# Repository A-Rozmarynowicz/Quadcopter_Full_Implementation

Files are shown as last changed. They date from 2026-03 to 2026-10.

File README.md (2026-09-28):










# Design and implementation of a quadrotor with a localization algorithm based on Ultra-Wideband beacons.

My Bachelor's project's task is to build a quadcopter from scratch, implement control and trajectory planning algorithms, synthesize a mathematical model, and develop an indoor positioning system. The expected outcome is a functional, maneuverable, and stable drone that is able to follow given trajectories.

Development time: from 01.2026 to 02.2027 (expected).

The project is also referred to as "Day One".

<p align="center">
  <picture>
    <source media="(prefers-color-scheme: dark)" srcset="Graphics\Logos\DayOne_Logo_White_on_Github.png">
    <source media="(prefers-color-scheme: light)" srcset="Graphics\Logos\DayOne_Logo_Black_on_White.png">
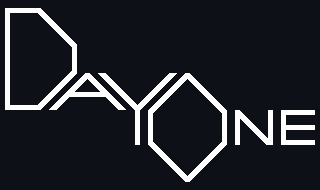
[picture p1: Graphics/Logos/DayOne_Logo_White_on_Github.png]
    
  </picture>
</p>

## Table of contents
* [Current progress](#current-progress)
* [General Information](#general-information)
* [UWB Positioning System](#uwb-positioning-system)
* [Technologies Used](#technologies-used)

## Current progress

The quadcopter has been assembled and it passed all the necessary hardware tests. That means the motors work, all chips are soldered correctly, and nothing is overheating. It lifts at around 35% motor power, and the battery lasts around 5 minutes in that setting. The machine is visible below.

<p align="center">
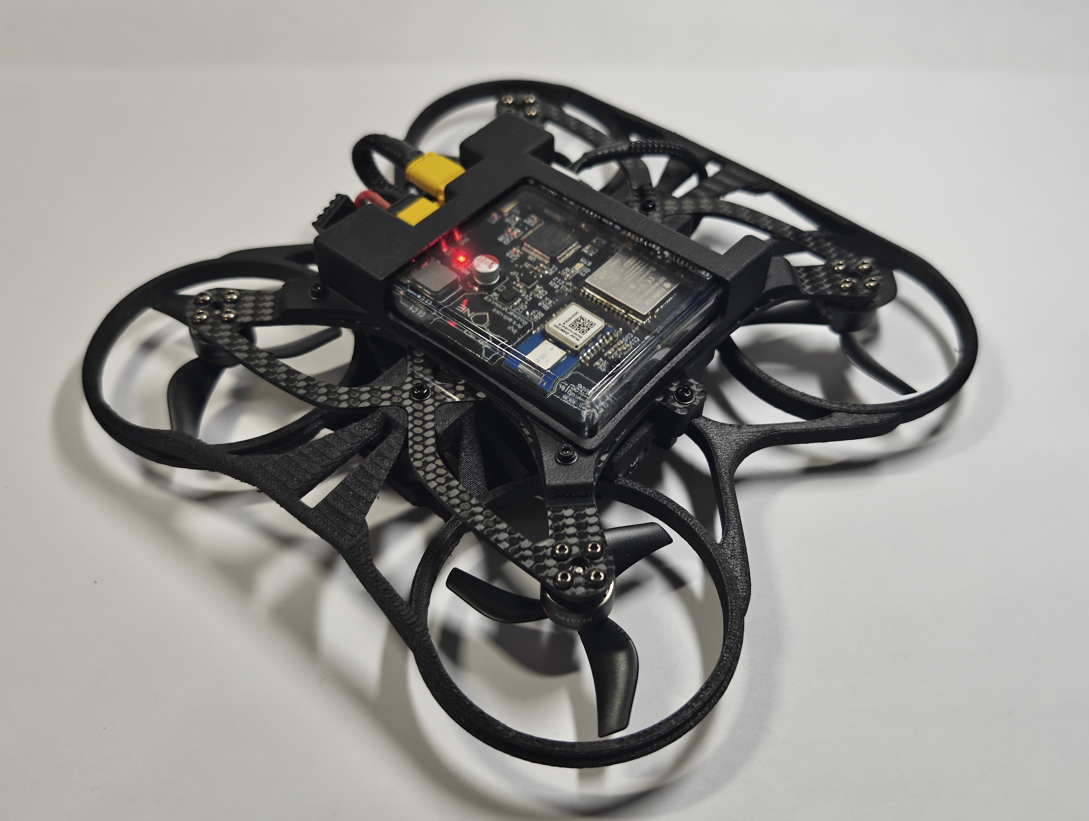
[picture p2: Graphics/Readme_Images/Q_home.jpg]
 <br>
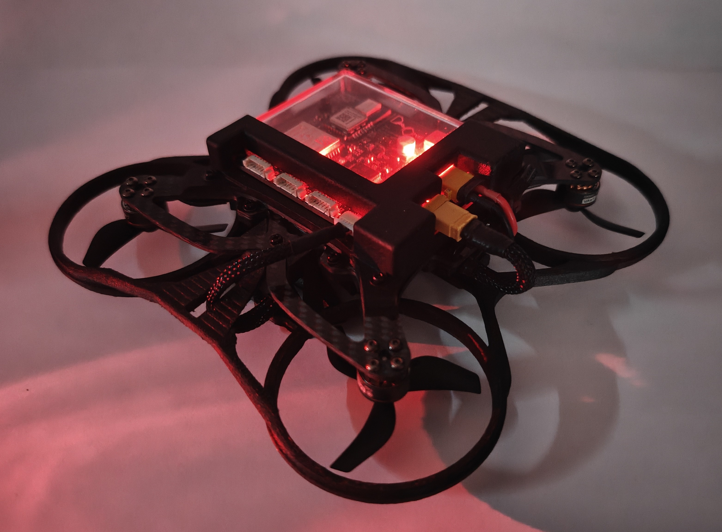
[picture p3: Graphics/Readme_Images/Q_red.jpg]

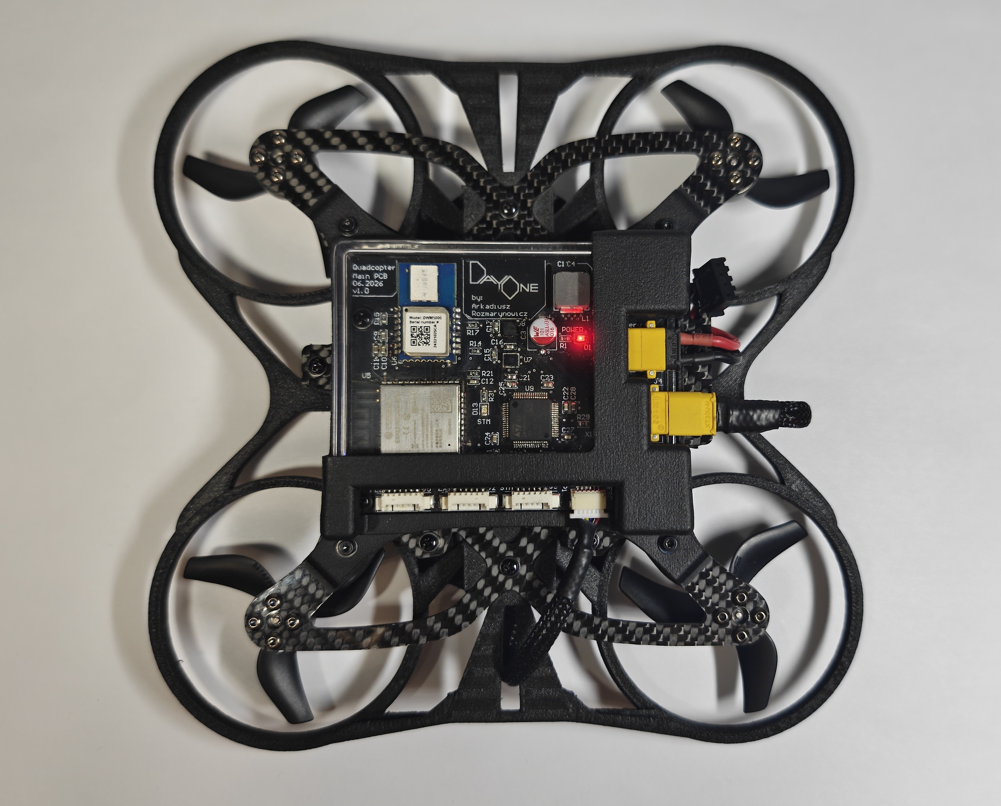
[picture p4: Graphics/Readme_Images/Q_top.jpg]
 <br>
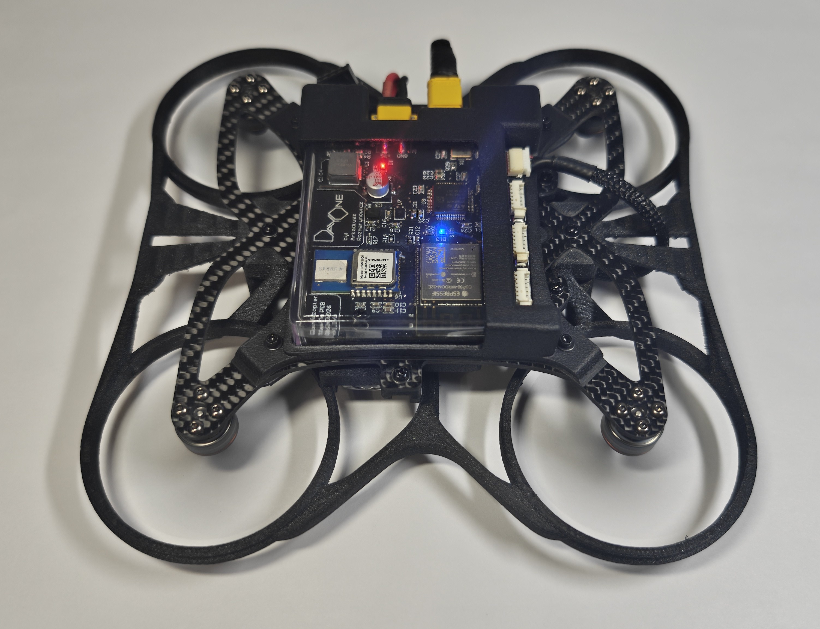
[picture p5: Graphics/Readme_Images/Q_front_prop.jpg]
 <br>
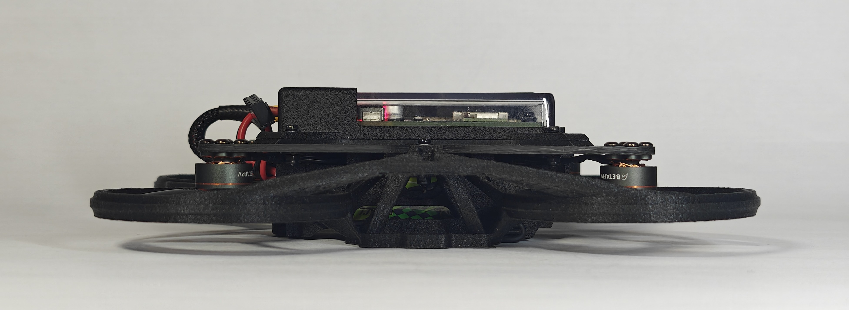
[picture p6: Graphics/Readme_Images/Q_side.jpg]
 <br>
<em>Figure 1: Quadcopter in real life.</em>
 </p>

The main PCB, visible in Figure 2, has been soldered manually and tested. The schematic document is available in this file: [.../Quadcopter_Main_PCB_Schematic.pdf](./Hardware/Electronics/Documents/Datasheets/Quadcopter_Main_PCB_Schematic.pdf).

<p align="center">
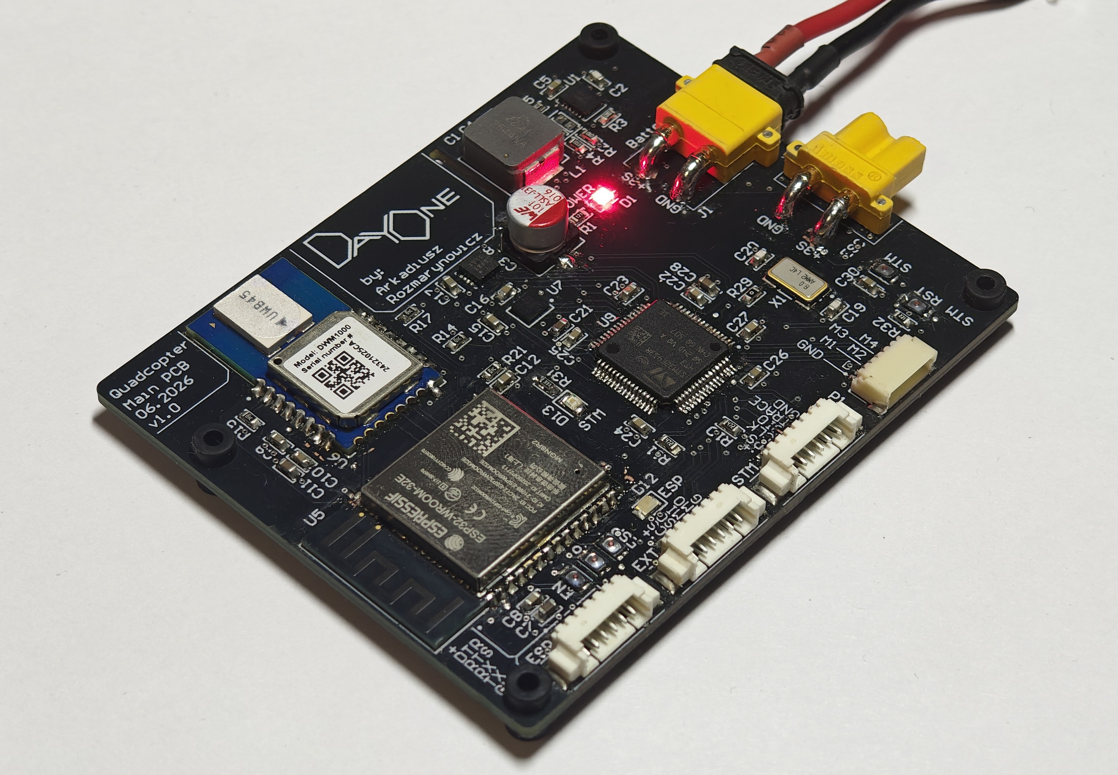
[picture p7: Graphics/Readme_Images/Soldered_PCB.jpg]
 <br>
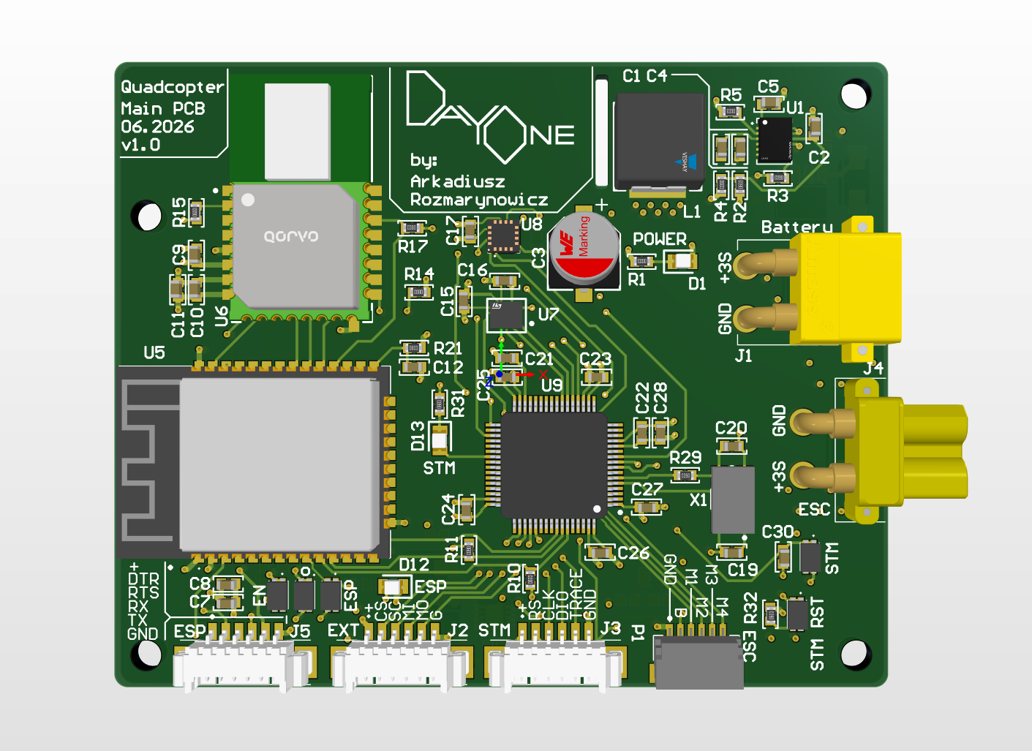
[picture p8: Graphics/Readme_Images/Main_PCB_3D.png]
Main PCB
 <br>
<em>Figure 2: 3D view of the quadcopter main PCB.</em>
 </p>

The current 3D model of the quadcopter is visible in Figure 3.

<p align="center">
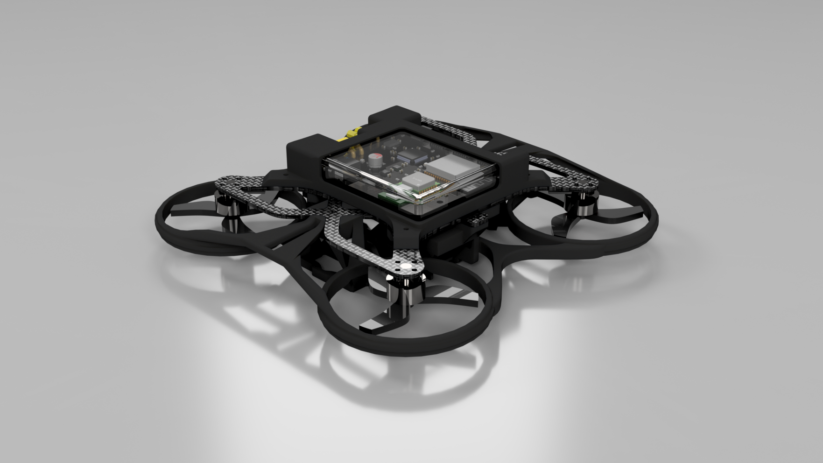
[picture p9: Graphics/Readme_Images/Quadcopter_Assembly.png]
Quadcopter Render
 <br>
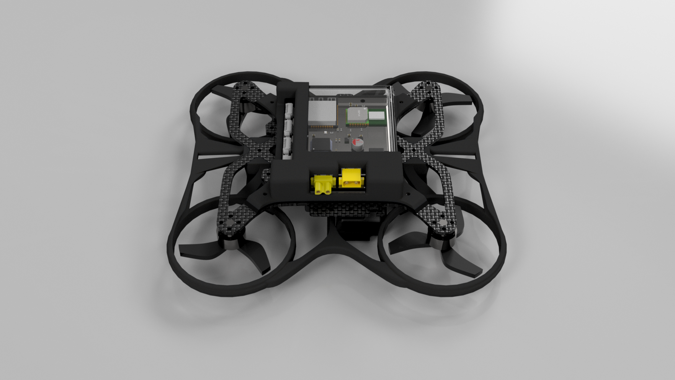
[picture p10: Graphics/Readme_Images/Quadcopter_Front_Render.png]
Quadcopter Render
 <br>
<em>Figure 3: 3D model of the quadcopter.</em>
 </p>

## General information

### Control Engineering
- Implementing a:
    - cascade 4-loop PID controller,
    - Kalman filter state estimator.
    - If time allows: polynomial decoupled trajectory planning based on given setpoints,
- Utilizing quaternions for attitude representation enabling more stable orientation control.
- If time allows: synthesizing a mathematical model of the drone to enable tuning the algorithms in simulation.
- Enabling manual override of the speed or attitude commands.

### Electronics
- An STM32F4 is used as the main MCU.
- An ESP32 onboard provides communication with a ground station and a custom positioning system (described later).
- IMU and a magnetometer support the positioning system in state estimation.
- Power source is a 680mAh, 3S, LiHV, lightweight, and small battery.
- Propellers are mounted on BLDC motors for high efficiency and power.
- The onboard power converter steps the voltage down to 3.3V.
- Safety measures are implemented to protect the device from overcurrent, overvoltage, reverse polarity, and ESD events.
- An off-the-shelf ESC drives the motors, commanded by the MCU's DShot signals.

### Mechanics
- Designing a custom:
    - carbon base plate for the robot,
    - housing for the PCBs,
    - shielding frame around the propellers,
    - battery slot.
- Total weight turned out to be 242 grams, which fits within the constraints set by the propellers' thrust: the drone lifts at around 35% motor power.

## UWB Positioning System
Part of the project is a custom positioning system that doesn't rely on a GPS signal. This is achieved by placing at least 4 Ultra-Wideband (UWB) modules near the area of the drone's operation. They measure their distance to the robot and estimate its relative position. This system is almost fully developed, and can be seen in this repository: [https://github.com/A-Rozmarynowicz/UWB_Positioning_System](https://github.com/A-Rozmarynowicz/UWB_Positioning_System).

<p align="center">
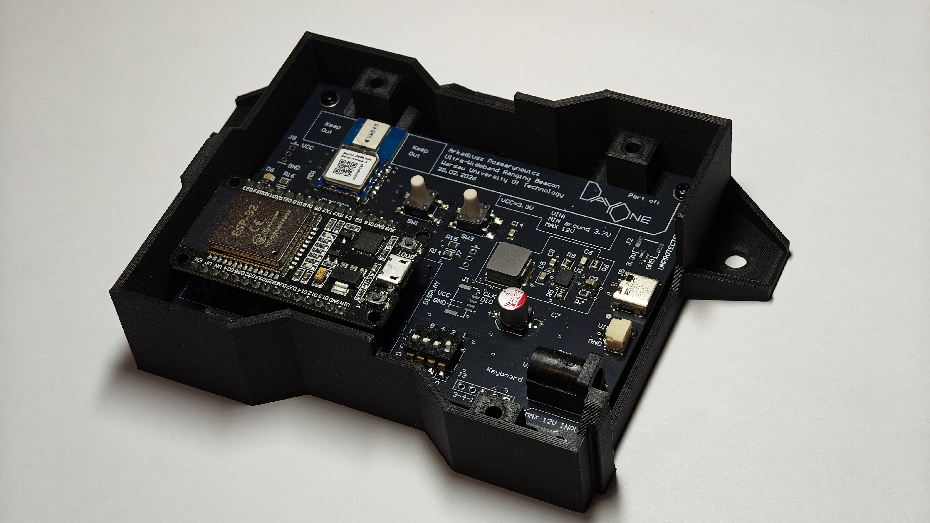
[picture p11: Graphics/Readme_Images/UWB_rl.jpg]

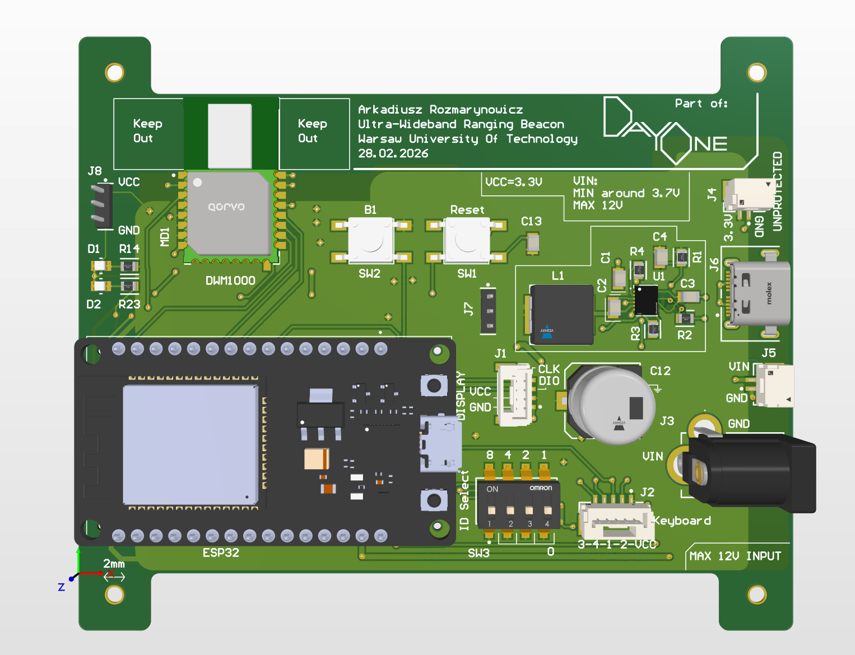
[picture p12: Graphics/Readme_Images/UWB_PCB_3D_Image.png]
 <br>
<em>Figure 4: UWB anchor.</em>
 </p>

## Technologies Used
- Ultra-Wideband radio technology
- Multiple communication protocols: SPI, I2C, UART, ESP-NOW, DShot
- Control engineering:
    - cascade PID
    - polynomial decoupled trajectory calculation
    - Kalman filter

- Programming languages:
    - C
    - C++
    - MATLAB

- Software used:
    - STM32 Cube IDE
    - Altium Designer
    - Autodesk Fusion
    - MATLAB
    - PlatformIO

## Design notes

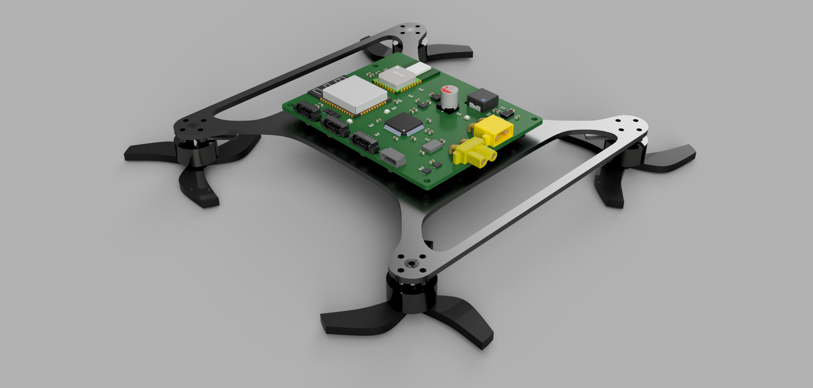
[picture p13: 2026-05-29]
Graphics/Readme_Images/Quadcopter_Frame_View.png

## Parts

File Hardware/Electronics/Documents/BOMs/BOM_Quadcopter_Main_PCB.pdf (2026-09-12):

Line # | Designator | Value | Quantity Part Number | Package | Supplier
13 | C1, C8, C9, C10, C12, C13, C14, C15, C16, C22, C23, C24, C25, C26, C27, C29, C30 | 100nF | 17 CC0603KRX7R8BB104 | 0603 | Mouser
15 | C2 | 27pF | 1 CC0603JRNP09BN270 | 0603 | Mouser
16 | C3 | 100µF | 1 865080545012 | | Mouser
12 | C4 | 4.7uF | 1 06035U4R7JAT2A | 0603 | Mouser
14 | C5, C17 | 1uF | 2 CC0603KRX5R6BB105 | 0603 | Mouser
17 | C6 | 22uF | 1 CC0603MRX6S4BB226 | 0603 | Mouser
1 | C7, C11, C28 | 2.2uF | 3 06036G225ZAT2A | 0603 | Mouser
18 | C18 | 10uF | 1 C0603C106M7PAC7411 | 0603 | Mouser
19 | C19, C20 | 30pF | 2 06031A300FAT2A | 0603 | Mouser
20 | C21 | 4.7uF | 1 06035U4R7JAT2A | 0603 | Mouser
23 | D1, D12, D13 | | 3 LS R976 | | Mouser
21 | D2, D3 | | 2 SMAJ12CA-HP6AT/13 | | Mouser
2 | D4, D6, D8, D9 | | 4 RCLAMP3354S.TCT | | Mouser
3 | D5, D7 | | 2 SMAJ12CA-HP6AT/13 | | Mouser
22 | D10 | | 1 ZMM33B | | Mouser
4 | D11 | | 1 AQ1205-01LTG | | Mouser
24 | F1 | | 1 0603L100SLYR | | Mouser
25 | J1 | | 1 XT30PW-M
5 | J2, J3, J5 | | 3 53261-0671 | | Mouser
26 | J4 | | 1 XT30PW-F
27 | L1 | | 1 IHLP3232DZER220M51 | | Mouser
6 | P1 | | 1 SM06B-SRSS-TB(LF)(SN) | | Mouser
29 | Q1, Q2 | | 2 SS8050-G | | Mouser
32 | R1, R26, R31 | 120R | 3 CR0603-JW-121ELF | 0603 | Mouser
30 | R2, R3, R5, R13 | 100k | 4 AF0603FR-13100KL | 0603 | Mouser
31 | R4 | 22.1k | 1 CRCW060322K1FKEBC | 0603 | Mouser
33 | R6, R7, R14, R15, R16, R17, R18, R19, R20, R21, R22, R23, R28, R30 | 10k | 14 CR0603AFX-1002EAS | 0603 | Mouser
7 | R8, R9, R24, R25, R27, R32, R33 | 220R | 7 CR0603-JW-221ELF | 0603 | Mouser
35 | R10, R11 | 4.7k | 2 AC0603JR-104K7L | 0603 | Mouser
34 | R12 | 270k | 1 CR0603-JW-274ELF | 0603 | Mouser
8 | R29 | 0R | 1 CR0603AJ/-000ELF | 0603 | Mouser
40 | SW1, SW2, SW3, SW4, SW5 | | 5 USLPT2616CT2TR | | Mouser
36 | U1 | | 1 ISL85410FRZ-T | | Mouser
37 | U2 | | 1 STEF4SPUR | | Mouser
38 | U3, U4 | | 2 DMP3056LSS-13 | | Mouser
9 | U5 | | 1 ESP32-WROOM-32E-N8R2 | | Mouser
28 | U6 | | 1 DWM1000 | | TME
39 | U7 | | 1 LSM6DSOTR | LGA-14L-DM00249496 Mouser
10 | U8 | | 1 MMC5983MA | | Mouser
11 | U9 | | 1 STM32F413RHT3 | | Mouser
41 | X1 | | 1 ABMM2-8.000MHZ-E2-T | | Mouser

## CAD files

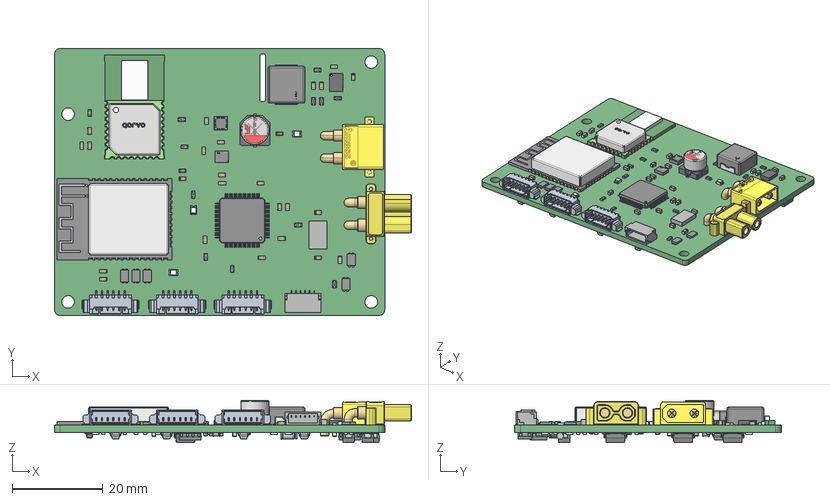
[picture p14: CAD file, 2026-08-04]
Hardware/Mechanics/PCBs/Quadcopter_Main_PCB.step
78.9 x 59.0 x 9.39 mm
capicitor_6.3x5.5x2.2
Base_Φ6_3Capacitor
0603 resistor x 33
terminal
pcb
antenna
pcb top
logo x 2
0603 cap x 29
ZMM33B
RCLAMP3354S.TCT x 4
SM06B-SRSS-TB_RGB8421504
AQ1205-01LTG
Pins x 5
Extruded
LS_R976 x 3
STM32F413RHT3
base
terminals
Logo x 2
MMC5983MA
Pieza141
Pieza142
Pieza143
Pieza143_10
Pieza143_26
Pieza143_44
Pieza143_17
Pieza143_21
Pieza143_37
Pieza143_35
Pieza143_16
Pieza143_3
Pieza143_18
Pieza143_5
Pieza143_31
Pieza143_33
Pieza143_2
Pieza143_4
Pieza143_34
Pieza143_24
Pieza143_15
Pieza143_22
Pieza143_36
Pieza143_32
Pieza143_6
Pieza143_19
Pieza143_23
Pieza143_41
Pieza143_7
Pieza143_20
Pieza143_38
Pieza143_11
Pieza143_8
Pieza143_39
Pieza143_40
Pieza143_9
Pieza143_25
Pieza143_42
Pieza143_43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

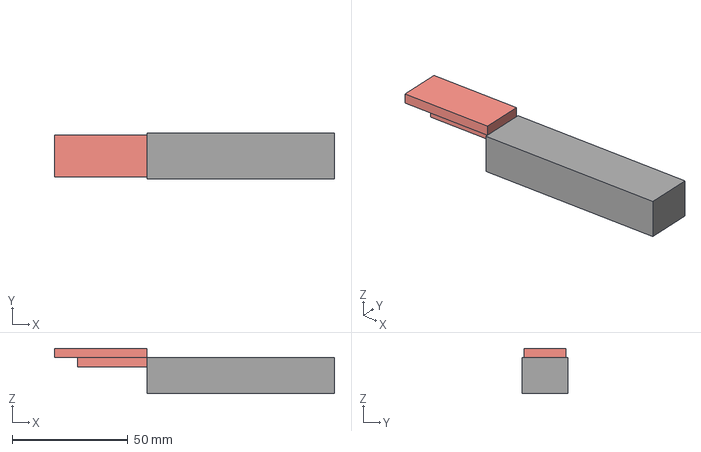
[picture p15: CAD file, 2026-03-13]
Hardware/Mechanics/Batteries/Battery_LAVA 2_3S_680mAh.step
121.0 x 20.0 x 19.5 mm

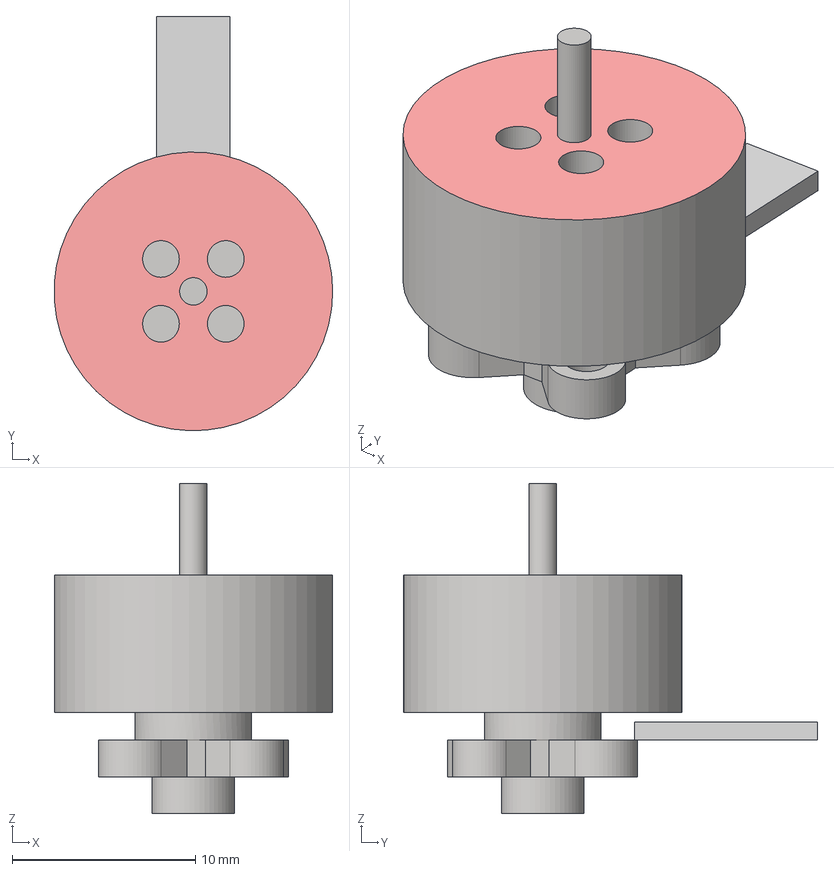
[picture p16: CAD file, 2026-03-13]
Hardware/Mechanics/Motors/BLDC_1104_7200KV.step
15.2 x 22.6 x 18.0 mm

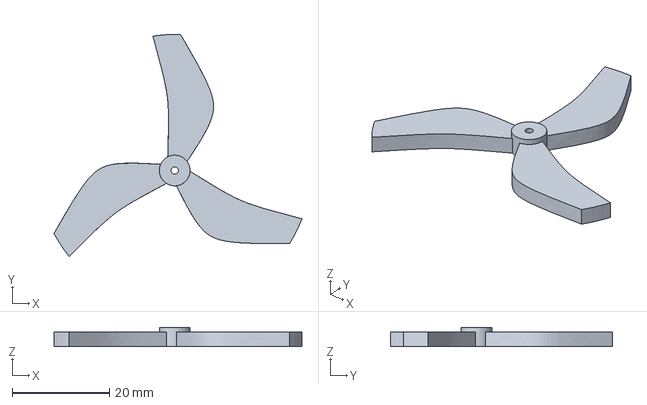
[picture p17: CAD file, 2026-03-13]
Hardware/Mechanics/Propellers/2218_3Blade/Propeller_2218_3Blade.step
50.9 x 45.6 x 4.00 mm

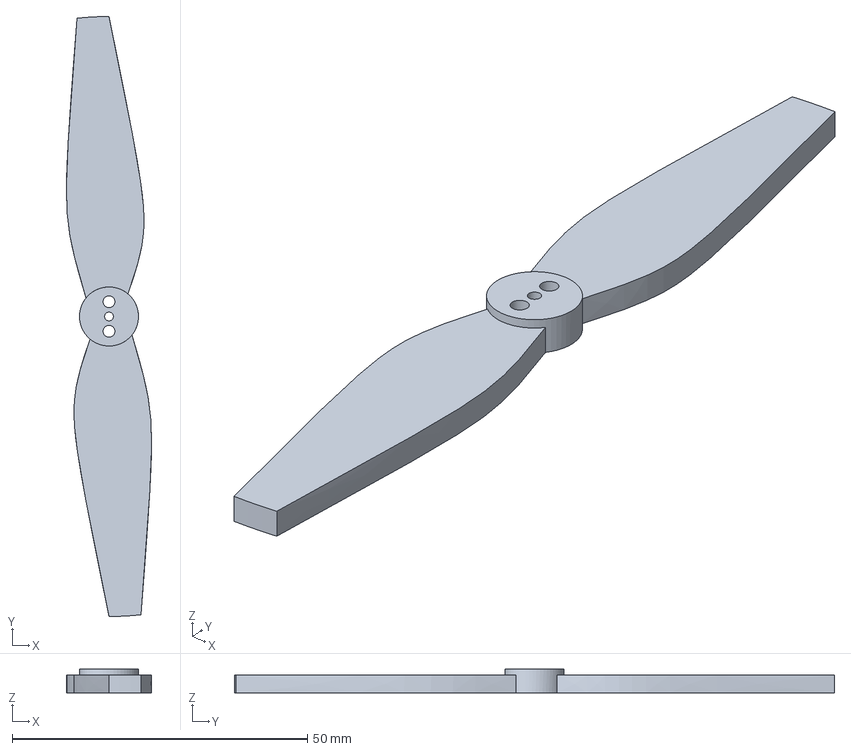
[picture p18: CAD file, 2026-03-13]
Hardware/Mechanics/Propellers/4025_2Blade/Propeller_4025_2Blade.step
14.4 x 101.6 x 4.00 mm

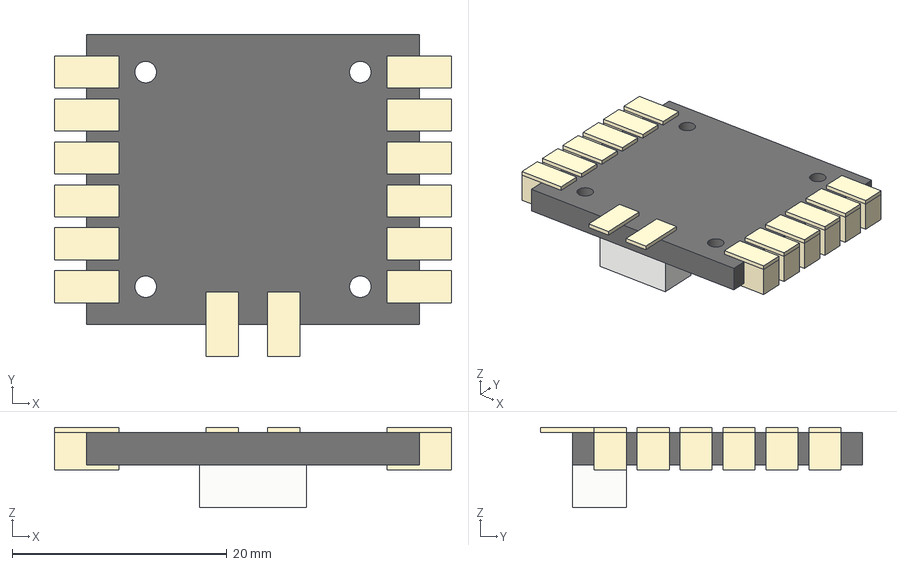
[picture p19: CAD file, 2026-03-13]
Hardware/Mechanics/PCBs/ESC_HAKRC_20A.step
37.0 x 30.0 x 7.50 mm

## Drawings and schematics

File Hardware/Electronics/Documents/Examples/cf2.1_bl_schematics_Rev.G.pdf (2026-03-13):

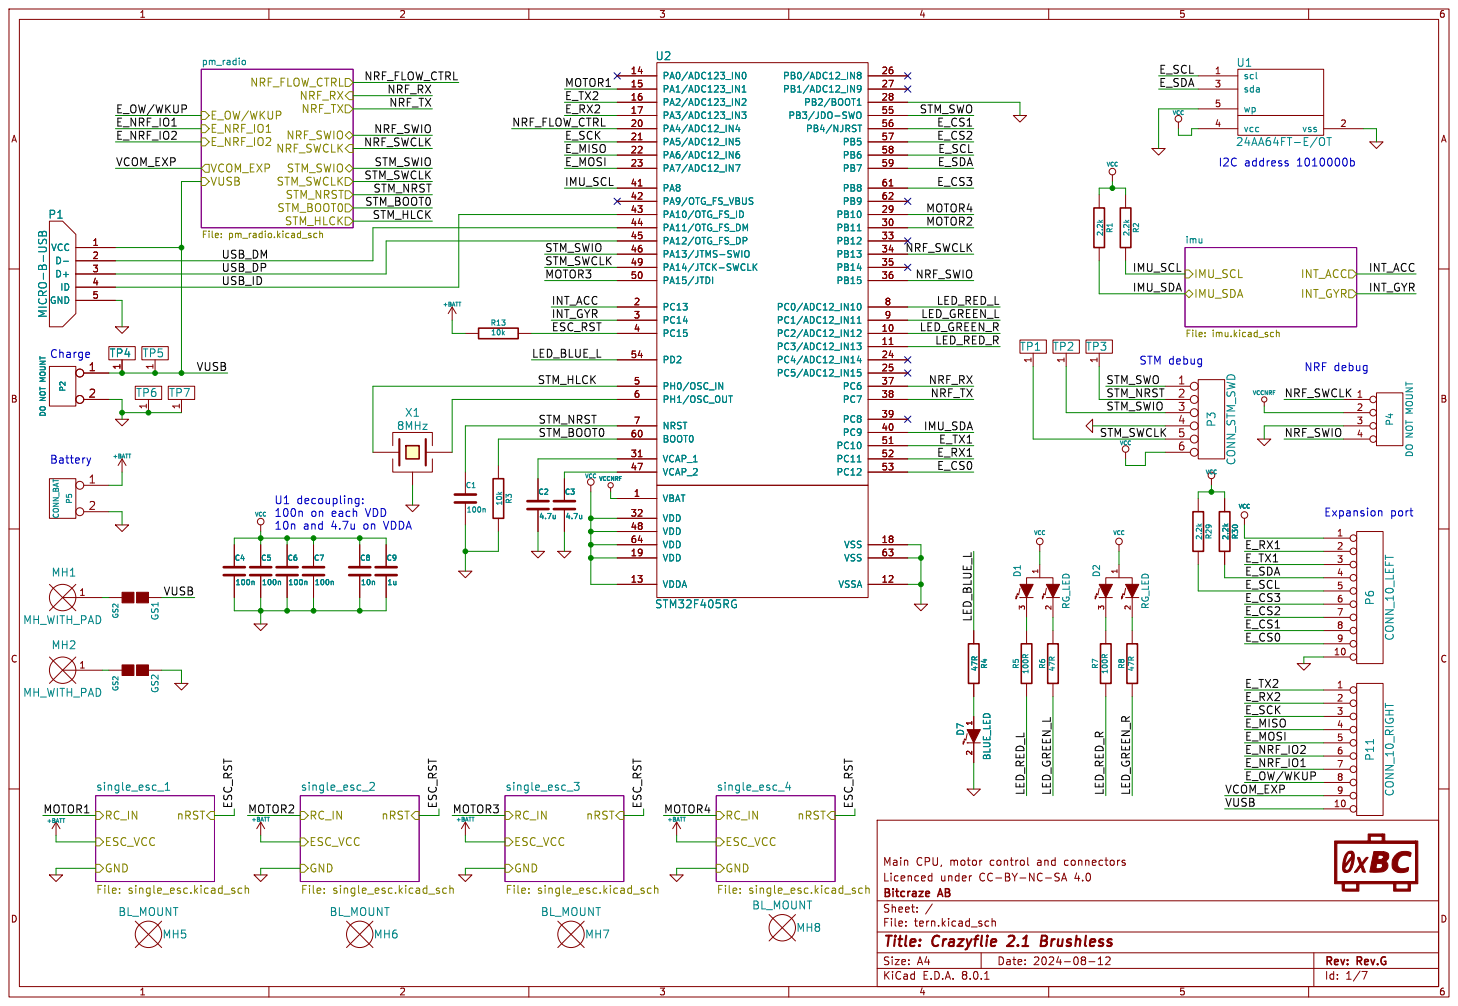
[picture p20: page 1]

I2C address 1010000b NRF debug STM debug

Expansion port U1 decoupling: 100n on each VDD

File: tern.kicad_sch Sheet: / Bitcraze AB

Id: 1/7 Title: Crazyflie 2.1 Brushless

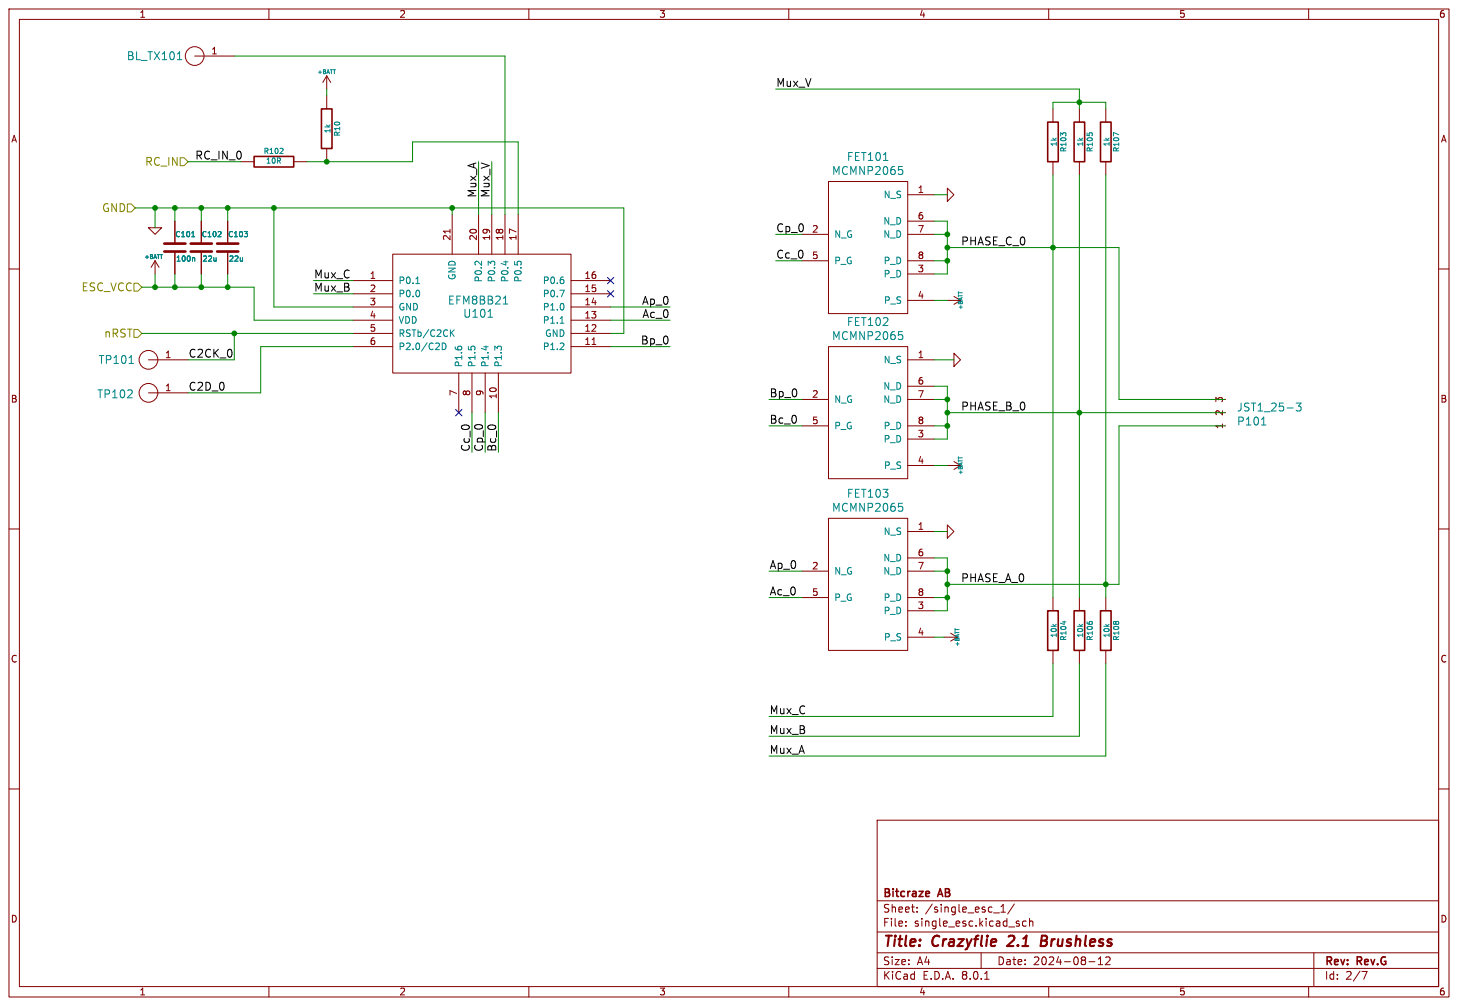
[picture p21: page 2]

Id: 2/7 Title: Crazyflie 2.1 Brushless

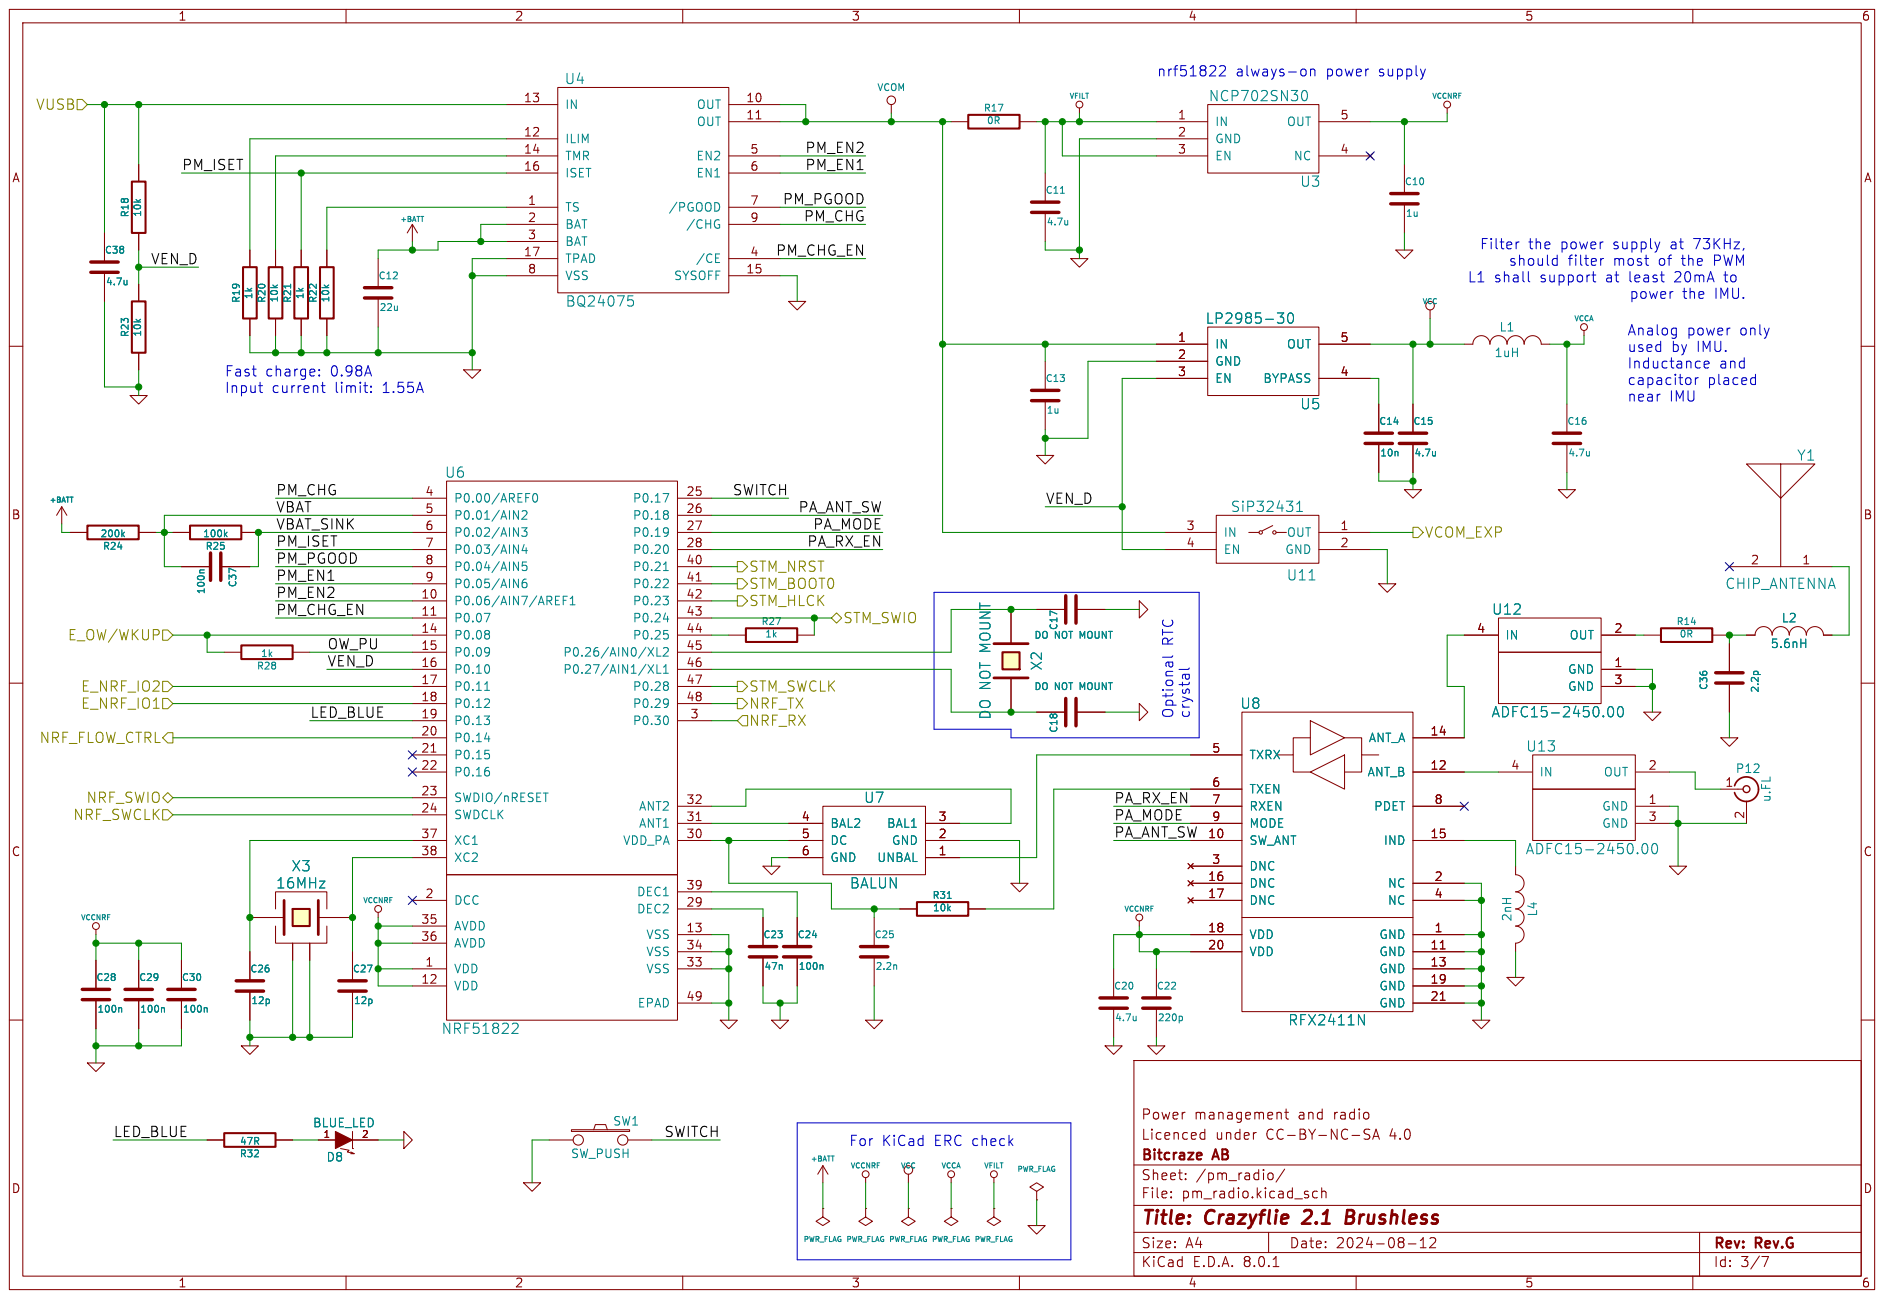
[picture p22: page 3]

L1 shall support at least 20mA to

power the IMU. Optional RTC crystal

Analog power only used by IMU.

2 P12 u.FL GND 1 OUT 2 GND 3

For KiCad ERC check

File: pm_radio.kicad_sch Sheet: /pm_radio/ Bitcraze AB

Id: 3/7 Title: Crazyflie 2.1 Brushless

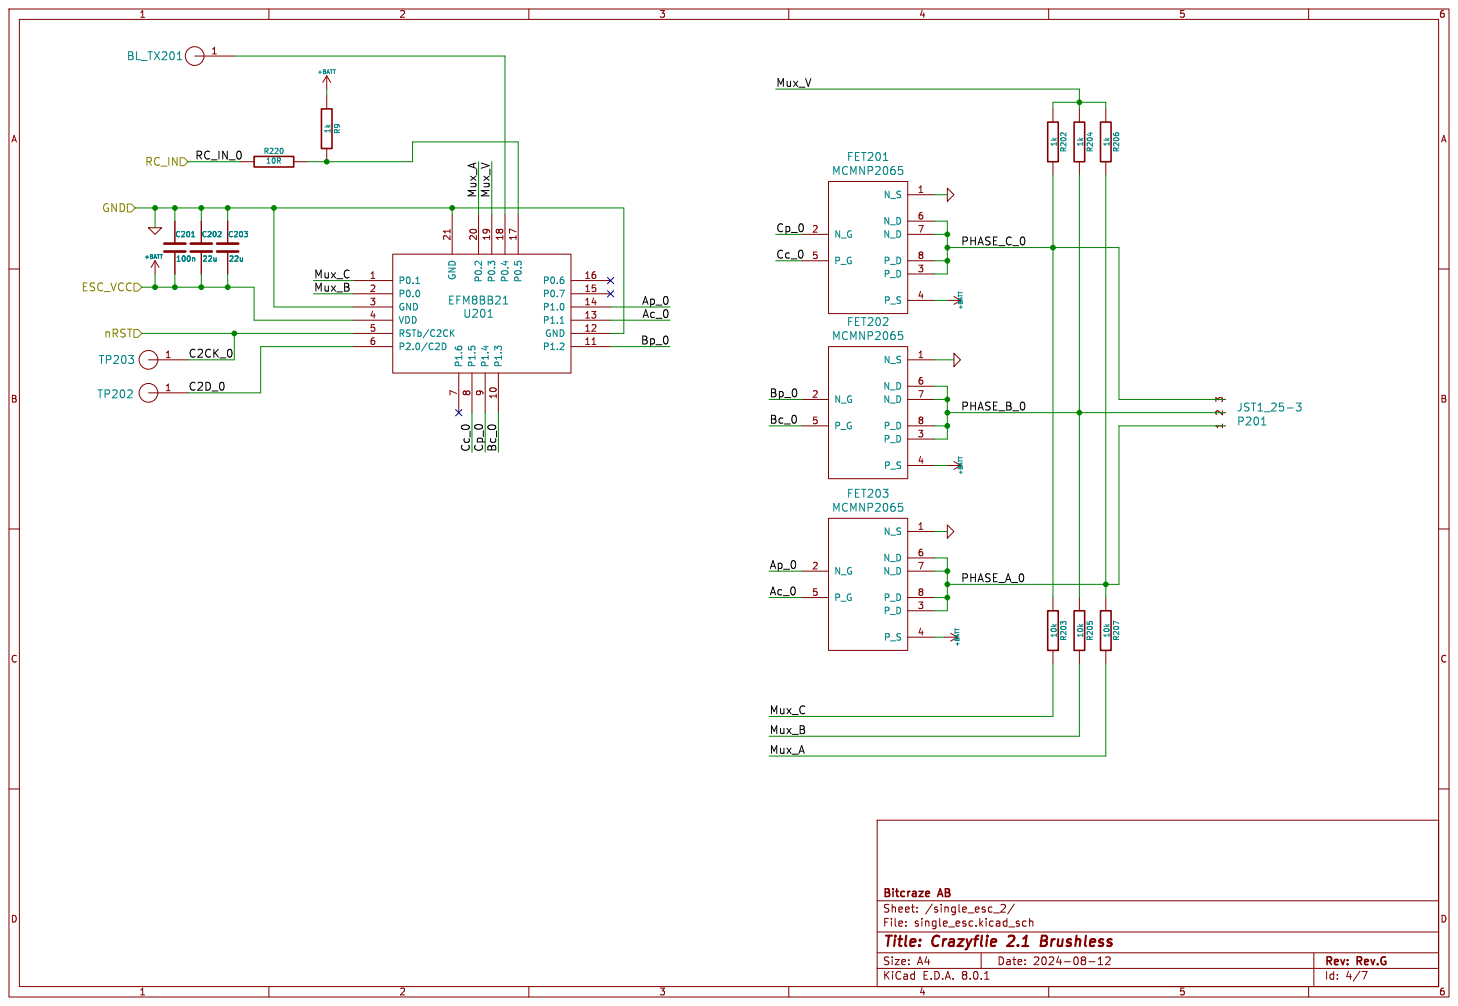
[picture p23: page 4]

File: single_esc.kicad_sch Sheet: /single_esc_2/ Bitcraze AB

Id: 4/7 Title: Crazyflie 2.1 Brushless

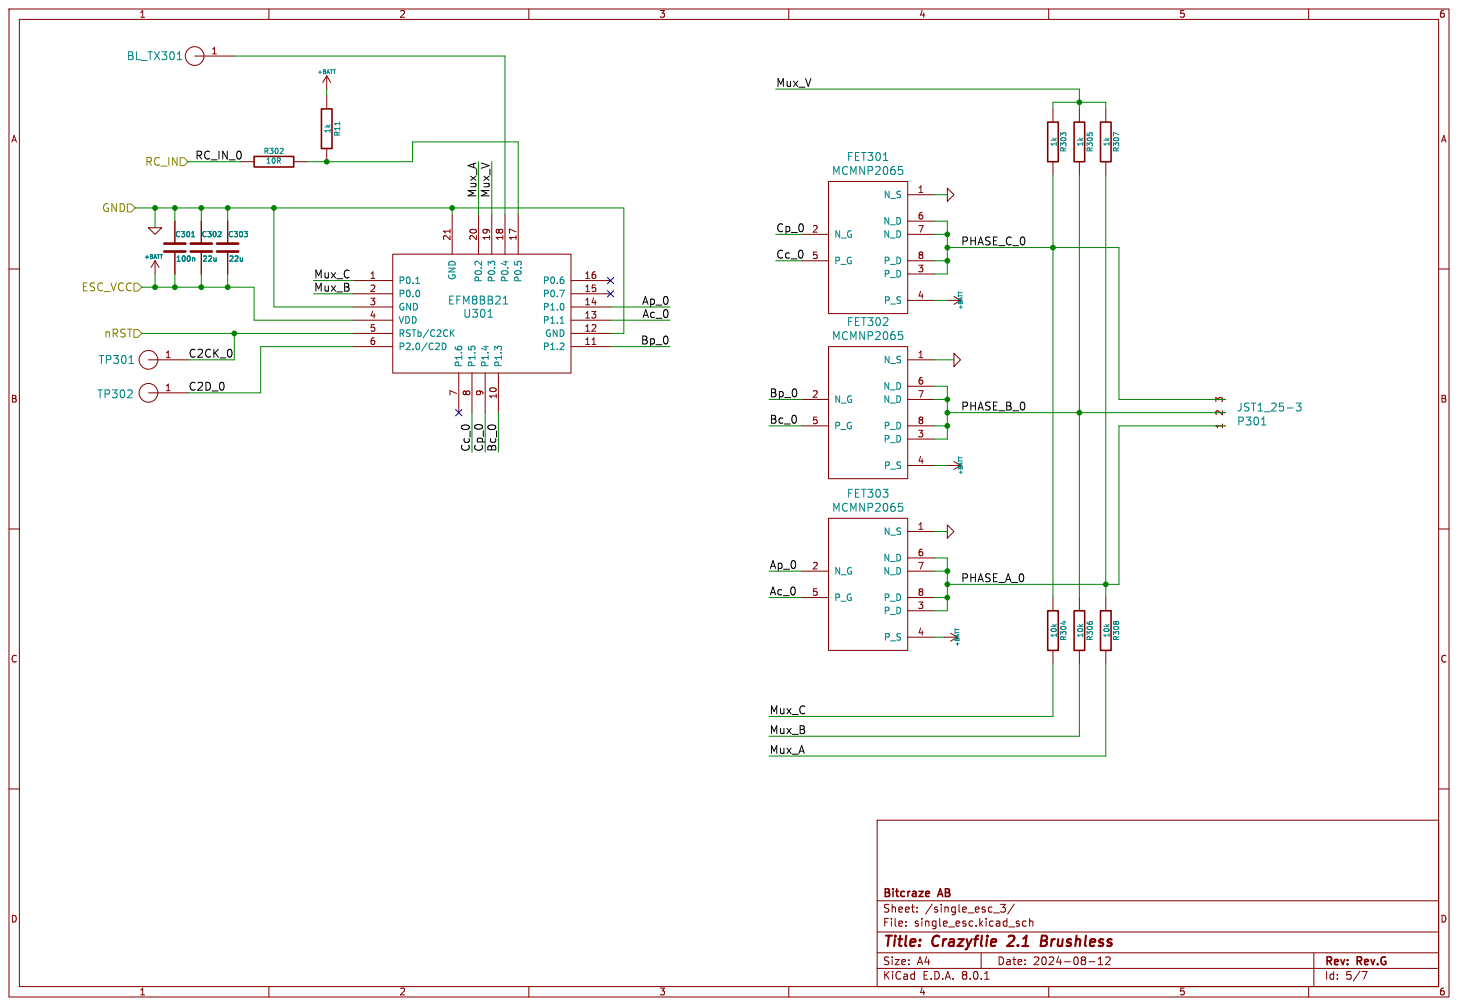
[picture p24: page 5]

File: single_esc.kicad_sch Sheet: /single_esc_3/ Bitcraze AB

Id: 5/7 Title: Crazyflie 2.1 Brushless

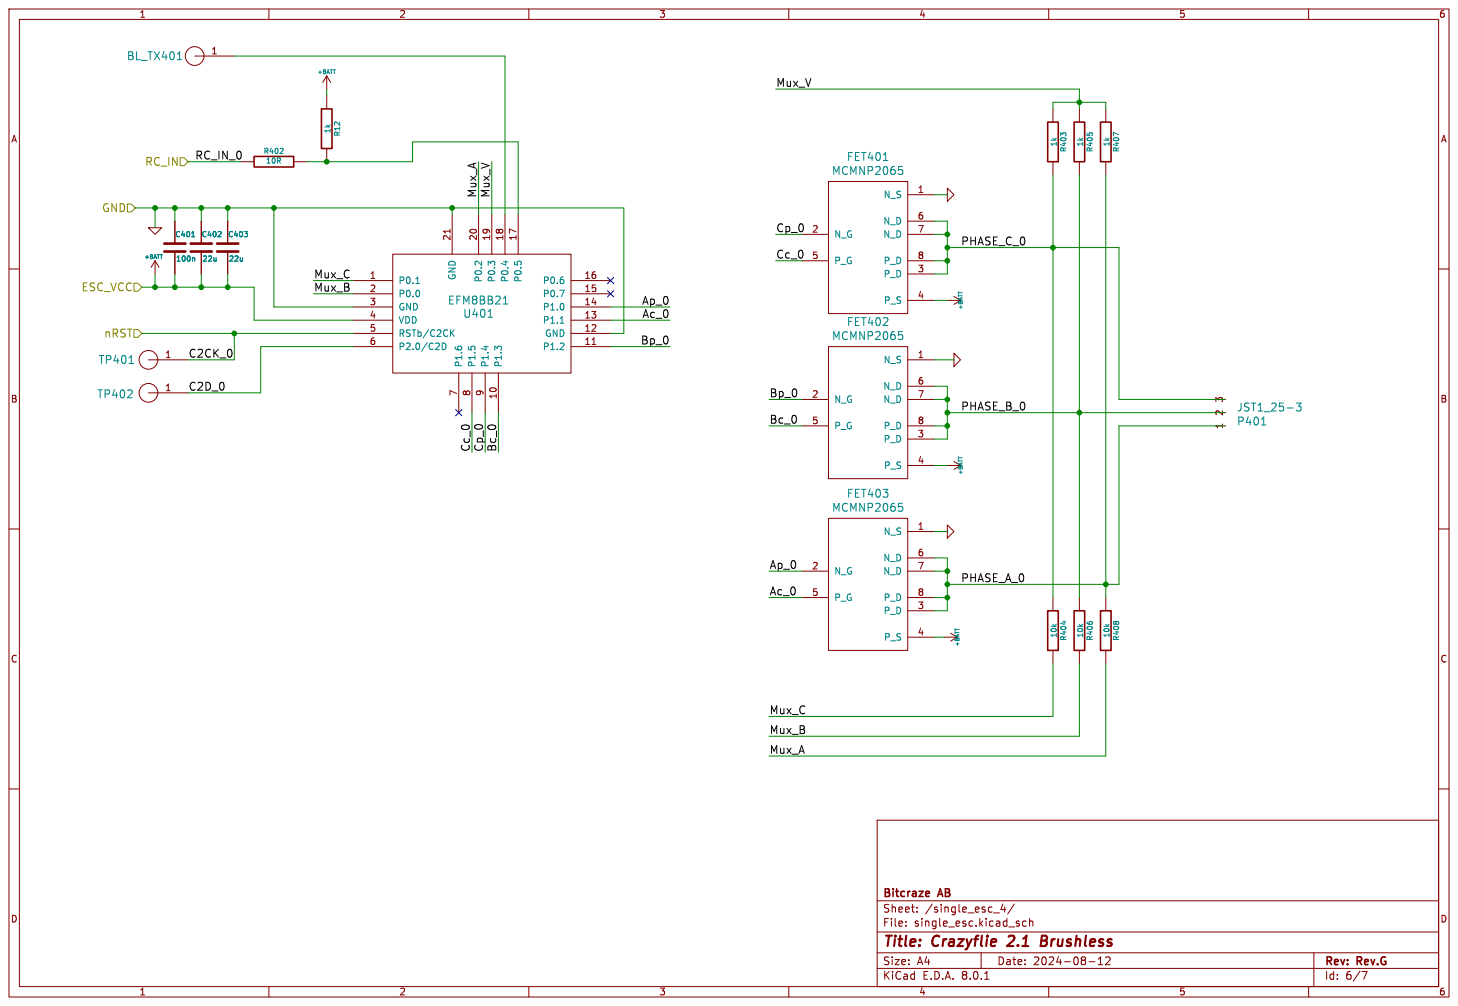
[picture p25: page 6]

Id: 6/7 Title: Crazyflie 2.1 Brushless

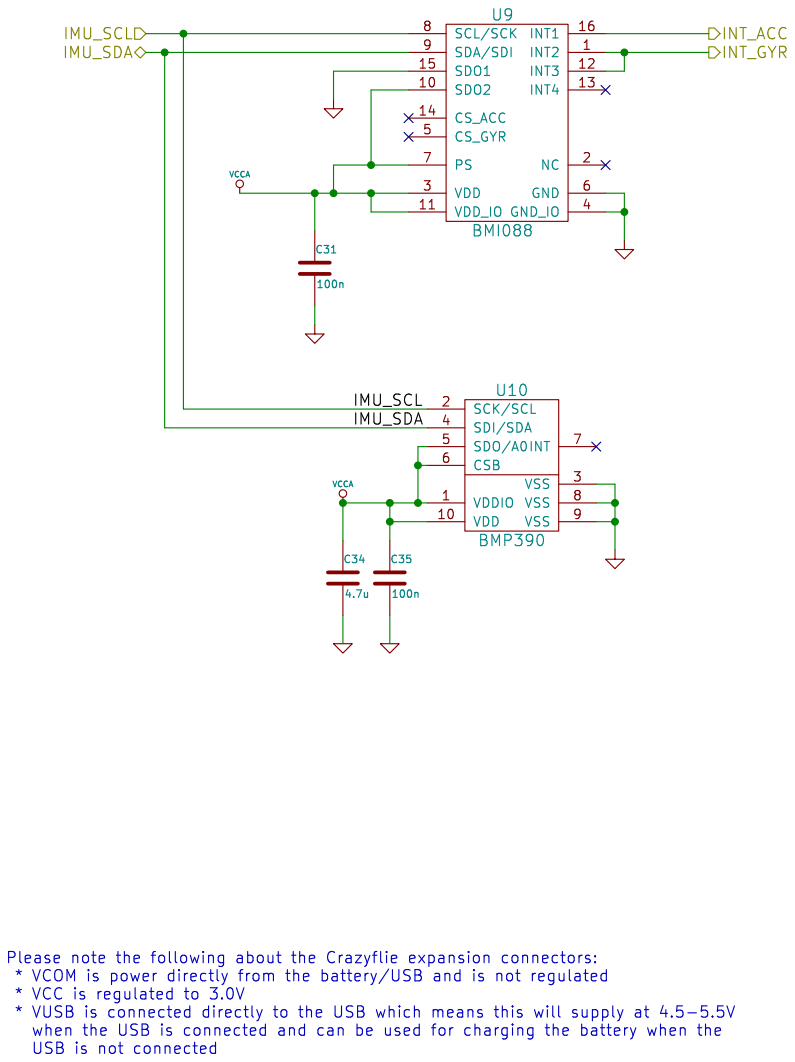
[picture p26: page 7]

File: imu.kicad_sch Sheet: /imu/ Bitcraze AB

Id: 7/7 Title: Crazyflie 2.1 Brushless

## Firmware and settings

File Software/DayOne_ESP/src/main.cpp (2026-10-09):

#include "Configuration.hpp"
#include "Timing.hpp"
#include "State_Machine.hpp"
#include "UWB.hpp"
#include "ESP_Communication.hpp"
#include "STM_Communication.hpp"

void Task_1ms();
void Task_5ms();
void Task_20ms();
void Task_100ms();
void Task_1000ms();


Timer_Handler::Timer_Config configs[] =
{
    { 1,    Task_1ms   },
    { 5,    Task_5ms   },
    { 20,   Task_20ms  },
    { 100,  Task_100ms },
    { 1000, Task_1000ms    }
};

Timer_Handler timer_handler(
    0,
    configs,
    sizeof(configs) / sizeof(configs[0])
);

State_Machine state_machine;


void setup() {
    Serial.begin(115200);
    timer_handler.Initialize();
    Initialize_ESP_Communication();
    Initialize_I2C();
    Initialize_UWB();
    state_machine.State_Machine_Initialize();
    Serial.println("Initialization complete\n");
}

void loop() {
    timer_handler.Update();
    Update_UWB();
}

void Task_1ms()
{
    state_machine.Task_1ms();
    state_machine.Handle_State_Change_Request();

    // Serial.println("1ms");
}

void Task_5ms()
{
    state_machine.Task_5ms();
    _send_esp();
    // Serial.println("5ms");
}

void Task_20ms()
{
    state_machine.Task_20ms();
    // Serial.println("20ms");
}

void Task_100ms()
{
    state_machine.Task_100ms();
    // Serial.println("100ms");
}

void Task_1000ms()
{
    state_machine.Task_1000ms();
    Flush_Unused_ESP_Received_Packets();
}

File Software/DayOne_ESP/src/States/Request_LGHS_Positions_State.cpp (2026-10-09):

#include "States.hpp"
#include "UWB.hpp"
#include "Positioning_Algebra_4LGHS.hpp"

void Request_LGHS_Positions_State::Enter()
{
    Reset_Requested_State();
    current_request_lgh_index = 0;
    ESP_MESSAGES::Send_Query_Position(current_request_lgh_index);
    Restart_UWB_As_Tag();
};

void Request_LGHS_Positions_State::Exit()
{
    current_request_lgh_index = 0;
    Reset_Requested_State();
}

void Request_LGHS_Positions_State::Task_1ms()
{

}

void Request_LGHS_Positions_State::Task_5ms()
{

}

void Request_LGHS_Positions_State::Task_20ms()
{

}

void Request_LGHS_Positions_State::Task_100ms()
{
    Check_For_Position_Response();
}

void Request_LGHS_Positions_State::Task_1000ms()
{
    missed_responses_counter++;
    if (missed_responses_counter >= 2)
    {
        // Serial.println("Resending position query");
        ESP_MESSAGES::Send_Query_Position(current_request_lgh_index);
        missed_responses_counter = 0;
    }
}

bool Request_LGHS_Positions_State::Check_For_Position_Response()
{
    if (Get_Requested_State() != STATES::NONE_STATE){return false;}
    ESP_Packet position_packet;
    Serial.printf("ESP rec stack Size: %d\n", esp_receive_queue.size());
    if (!Search_For_ESP_Command(position_packet, ESP_Data_Commands::OBSERVER_RESPONSE_POSITION))
    { return false; }
    Serial.printf("Received some packet from %d vs needed %d\n", position_packet.data[ESP_Data_Setup::TRANSMITTER_ID], current_request_lgh_index);
    if (position_packet.data[ESP_Data_Setup::TRANSMITTER_ID] != current_request_lgh_index)
    {
        return false;
    }
    Serial.println("Received packet");
    missed_responses_counter = 0;
    Position position;
    memcpy(&position.x, &position_packet.data[QUAD_0], sizeof(float));
    memcpy(&position.y, &position_packet.data[QUAD_1], sizeof(float));
    memcpy(&position.z, &position_packet.data[QUAD_2], sizeof(float));
    Update_LGH_Position(position, current_request_lgh_index);
    Serial.printf("Lighthouse: %d, x: %0.2f, y: %0.2f, z:%0.2f\n", current_request_lgh_index, position.x, position.y, position.z);
    Handle_Increment_Next_LGH_Query();
    // esp_receive_queue.flush();
    return true;
}

void Request_LGHS_Positions_State::Handle_Increment_Next_LGH_Query()
{
    if (current_request_lgh_index >= NUMBER_OF_LIGHTHOUSES-1)
    {
        ALGEBRA_4LGHS::Build_Constant_Matrices(lighthouse_positions_by_indices);
        Request_Change_State(STATES::FLIGHT_STATE);
        return;
    }

    current_request_lgh_index++;
    ESP_MESSAGES::Send_Query_Position(current_request_lgh_index);
}

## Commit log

2026-03-13 Added an existing UWB Beacon Altium project
    [Connectors.SchDoc, Interface.SchDoc, Microcontrollers.SchDoc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]
2026-03-13 Added motor STEP file
    [BLDC_1104_7200KV.step, Connectors.SchDoc, Interface.SchDoc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]
2026-03-13 Added propellers STEP files
    [Propeller_2218_3Blade.step, Propeller_4025_2Blade.step]
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2026-03-13 Added battery STEP file
    [Battery_LAVA 2_3S_680mAh.step]
2026-03-13 Cleaned STEP folders hierarchy
    [BLDC_1104_7200KV.step, Battery_LAVA 2_3S_680mAh.step, ESC_HAKRC_20A.step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]
2026-03-13 Cleaned Mechanics folders hierarchy
    [BLDC_1104_7200KV.step, Battery_LAVA 2_3S_680mAh.step, ESC_HAKRC_20A.step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]
2026-03-16 Moved Altium project to a different repo
    [Connectors.SchDoc, Interface.SchDoc, Microcontrollers.SchDoc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]
2026-03-16 Removed 3D UWB Beacon files
    [UWB_Casing_Bottom.step]
2026-03-16 Moved up 3D files up a folder
    [BLDC_1104_7200KV.step, Battery_LAVA 2_3S_680mAh.step, ESC_HAKRC_20A.step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]
2026-03-31 Created the quadcopter main PCB project
    [Quadcopter_Main_PCB.PrjPcb]
2026-03-31 Added the power schematic
    [Power.SchDoc, Quadcopter_Main_PCB.PrjPcb]
2026-04-08 Begining to work on the main PCB
    [Power.SchDoc, Quadcopter_Main_PCB.PcbDoc, Quadcopter_Main_PCB.PrjPcb]
2026-04-19 Working on power converter
    [Power.SchDoc]
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2026-04-20 Adding power protection for programming connectors
    [Connectors.SchDoc, Power.SchDoc, Quadcopter_Main_PCB.PcbDoc]
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2026-04-20 Added battery and esc connectors
    [Connectors.SchDoc]
2026-04-20 Created UWB Positioning schematic
    [Power.SchDoc, UWB_Positioning.SchDoc, main.SchDoc]
2026-04-20 Fixed P-Mosfet 3D body not showing
    [Connectors.SchDoc, Power.SchDoc, Quadcopter_Main_PCB.PcbDoc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]
2026-04-20 Added TVS diodes to connectors
    [Connectors.SchDoc, Power.SchDoc, Quadcopter_Main_PCB.PcbDoc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]
2026-04-20 Added DWM1000 and esp32
    [Connectors.SchDoc, Quadcopter_Main_PCB.PcbDoc, UWB_Positioning.SchDoc]
2026-04-20 Added STm32 and sensors schematics
    [STM32.SchDoc, Sensors.SchDoc, main.SchDoc]
2026-04-20 Fixed power EN: now is high
    [Power.SchDoc, Sensors.SchDoc, main.SchDoc]
2026-04-20 Fixed resistors and capacitors values after library reload
    [Connectors.SchDoc, Power.SchDoc, Sensors.SchDoc]
2026-04-21 Adding UWB System connections
    [Power.SchDoc, Quadcopter_Main_PCB.PrjPcb, Sensors.SchDoc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]
2026-04-21 Adding ESP32 boot and reset functionalities
    [UWB_Positioning.SchDoc]
2026-04-21 Working on UWB SPI
    [UWB_Positioning.SchDoc]
2026-04-21 ESP32 Strapping pins ok
    [Quadcopter_Main_PCB.PrjPcb, Sensors.SchDoc, UWB_Positioning.SchDoc]
2026-04-22 Added ports to UWB schematic
    [UWB_Positioning.SchDoc, main.SchDoc]
2026-04-22 Changed all resistors and capacitors to 0603 in UWB schematic
    [UWB_Positioning.SchDoc]
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2026-04-22 Cleaning up the UWB schematic
    [UWB_Positioning.SchDoc]
2026-04-22 Added an example bitcraze datasheet
    [Power.SchDoc, UWB_Positioning.SchDoc]
2026-04-22 Added magnetometer ports in the Sensors schematic
    [Sensors.SchDoc]
2026-04-22 Added connections to the IMU
    [Sensors.SchDoc]
2026-04-22 Cleaned up the Sensors schematic
    [Sensors.SchDoc]
2026-04-22 Updated all capacitor symbols from libraries
    [Power.SchDoc, Sensors.SchDoc]
2026-04-22 Cleaned up Power schematic after library update
    [Power.SchDoc]
2026-04-22 Updated Sensors schematic after capacitor librabry update
    [Sensors.SchDoc]
2026-04-22 Cleaned up UWB schematic after capacitor library update
    [Sensors.SchDoc, UWB_Positioning.SchDoc]
2026-04-22 Synchronized sheet entries and ports
    [Connectors.SchDoc, Sensors.SchDoc, UWB_Positioning.SchDoc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]
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2026-04-23 Added ports to STM32 schematic
    [STM32.SchDoc]
2026-04-23 Choosing pins on the STM32
    [STM32.SchDoc, UWB_Positioning.SchDoc]
2026-04-23 Created interface schematic for STM32
    [Interface_STM32.SchDoc, Power.SchDoc, STM32.SchDoc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]
2026-04-23 Added pusbuttons and LED to the STM32_Interface
    [Interface_STM32.SchDoc, Power.SchDoc, STM32.SchDoc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]
2026-04-23 Adding communication ports to STM32
    [Interface_STM32.SchDoc, Power.SchDoc, STM32.SchDoc]
2026-04-23 Cleaned up STM32 schematic
    [STM32.SchDoc]
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2026-04-24 Added notes in STM32 schematic
    [Quadcopter_Main_PCB.PrjPcb, STM32.SchDoc]
2026-04-24 Replacing STM32L4 with STM32F4
    [Quadcopter_Main_PCB.PcbDoc, STM32.SchDoc]
2026-04-24 Deleted STM32L4 from the schematic
    [Quadcopter_Main_PCB.PcbDoc, STM32.SchDoc]
2026-04-24 Cleaned up pin positioning on the STM32F4
    [STM32.SchDoc]
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2026-04-26 Added external interrupts pins in STM32 for magnetometerand IMU
    [STM32.SchDoc, UWB_Positioning.SchDoc]
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2026-04-27 Fixed off grid ports error
    [Connectors.SchDoc, Interface_STM32.SchDoc, STM32.SchDoc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]
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2026-04-27 Renamed nets in UWB to fix errors
    [Connectors.SchDoc, Interface_STM32.SchDoc, Quadcopter_Main_PCB.PcbDoc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]
2026-04-27 Changed settings, now ports and sheet entries dont name nets
    [Connectors.SchDoc, Power.SchDoc, Quadcopter_Main_PCB.PrjPcb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]
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2026-04-29 Replaced USB C model with the correct one
    [Connectors.SchDoc, Quadcopter_Main_PCB.PrjPcb, STM32.SchDoc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]
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2026-05-01 Moved the battery measurement circuit to connectors schematic
    [Connectors.SchDoc, Power.SchDoc]
2026-05-01 Swapped order of tracks on ESC connector
    [Connectors.SchDoc, Power.SchDoc, Quadcopter_Main_PCB.PcbDoc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]
2026-05-01 Removed pulldown resistor on STM status button, added series resistor instead
    [Interface_STM32.SchDoc, Power.SchDoc, Quadcopter_Main_PCB.PcbDoc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]
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2026-05-01 Connected stm32 SPI3 ports to connector redundant ports
    [Connectors.SchDoc, main.SchDoc]
2026-05-01 Replaced 8-pin molex with 6-pin
    [Connectors.SchDoc, main.SchDoc]
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2026-05-02 Added a spare molex connector for the ESC
    [Connectors.SchDoc]
2026-05-02 Replaced STM32 IDC programmin socket with a molex picoblade
    [Connectors.SchDoc]
2026-05-02 Replaced ESP32 programming header with molex picoblade
    [Connectors.SchDoc]
2026-05-02 Resetted and reannotated all designators
    [Connectors.SchDoc, Quadcopter_Main_PCB.PcbDoc]
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2026-05-06 Added 2 bulk capacitors, no schematic errors
    [STM32.SchDoc, UWB_Positioning.SchDoc, main.SchDoc]
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2026-05-08 Fixed all current DRC errors
    [Quadcopter_Main_PCB.PcbDoc]
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2026-05-11 Fixed all DRC errors
    [Connectors.SchDoc, Interface_STM32.SchDoc, Quadcopter_Main_PCB.PcbDoc]
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2026-05-28 Swapped places of ESC connectro and stm buttons
    [Quadcopter_Main_PCB.PcbDoc]
2026-05-28 Swapped places of the ESC connector and STM buttons
    [Quadcopter_Main_PCB.PcbDoc]
2026-05-29 Generated a new step file for the main PCB
    [Quadcopter_Main_PCB.step]
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2026-06-05 Fixed DRC for hole size
    [Quadcopter_Main_PCB.PcbDoc]
2026-06-05 Exported a pdf datasheet for the main PCB
    [Quadcopter_Main_PCB.PcbDoc]
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2026-08-23 Reworked Molex adapter PCB
    [Molex_Programming_Adapter.PcbDoc]
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2026-10-09 Fixed circular dependecies: no warnings
    [Request_LGHS_Positions_State.cpp]
2026-10-09 Fixed a bug with flushing esp receive packets: program progresses to state 2
    [Request_LGHS_Positions_State.cpp]
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2026-10-20 Flight_State no longer decides whether to Parse_Measurements, it just does it at 10Hz
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2026-10-22 Resolved inheritance issues in Sensor
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2026-10-25 Fixed a bug in Magnetometer::DMA_TxRxCompleteCallback(): wrong arguments, no state change
2026-10-25 Fixed a bug in Magnetometer::Clear_Interrupt():no state change
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2026-10-25 Failed to receive interrupt from Magnetometer
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2026-10-26 Fixed Magnetometer to clear CS pin in Set, Reset, Enable_Measurement states
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2026-10-26 Magnetometer now repeats its state when DMA transfer fails
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2026-10-29 Implemented software reset for IMU
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2026-10-29 Testing I2C communication: fail for now
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2026-11-04 Fixed: state in Kalman filtered was incorrectly accessed by []
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
